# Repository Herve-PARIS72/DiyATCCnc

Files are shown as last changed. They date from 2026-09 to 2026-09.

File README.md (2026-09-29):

# DiyATCCnc

Prototype DIY de magasin linéaire à quatre douilles sur ressort pour une **CNC 3018**. Conception paramétrique OpenSCAD, fichiers STL et documentation en français.

**Version mécanique actuelle : V3. Les douilles restent entièrement sous le couvercle**, même au repos. Le couvercle laisse passer les écrous et retient les douilles. Les ressorts autorisent une descente de 4 mm, et des ergots internes empêchent la rotation des douilles.

> État réel : prototype d'ajustement manuel, pas un changeur automatique opérationnel. Les ressorts ne sont pas sélectionnés, le serrage n'est pas validé et aucune retenue de fraise desserrée n'est prévue. Ne pas lancer de serrage motorisé dans les pièces imprimées.

## Télécharger et ouvrir

- [Source OpenSCAD complet](cad/ATC_4_douilles_ressorts.scad)
- STL : [bloc](stl/bloc.stl), [couvercle](stl/plaque.stl), [douille](stl/douille.stl), [fond](stl/fond.stl)
- [Montage et impression](docs/MONTAGE.md)
- [Dimensions et ressorts](docs/CONCEPTION.md)
- [Matériel et intégration FluidNC](docs/ELECTRONIQUE.md)
- [Notice détaillée V3](docs/NOTICE_V3.txt)
- [Calibres pour l'écrou de 17 mm](calibres/)
- [Historique et limites](docs/HISTORIQUE.md)

Imprimer **1 bloc, 1 couvercle, 1 fond et 4 douilles**. Dans GitHub, les fichiers STL peuvent être visualisés individuellement ; utiliser le téléchargement du fichier pour les ouvrir dans un trancheur.

Dans OpenSCAD, modifier `piece` :

```scad
piece = "assemblage"; // Vue complète
// "coupe"      : coupe de contrôle de l'intérieur
// "bloc"       : corps seul
// "plaque"     : couvercle seul
// "douille"    : douille seule, à imprimer 4 fois
// "fond"       : fond avec guides de ressort et butées
// "impression" : toutes les pièces disposées à plat
```

Utiliser F5 pour l'aperçu et F6 avant export STL. Les ressorts affichés sont schématiques et ne sont pas exportés. Exporter les pièces séparément, pas l'assemblage en contact.

Pour montrer la position basse :

```scad
enfoncement = 4; // entre 0 et course
```

## Matériel déclaré

| Élément | Information connue |
|---|---|
| Machine | CNC 3018, variante exacte non documentée |
| Carte | ESP32, firmware FluidNC déclaré par l'utilisateur |
| Broche | Alimentation 24 V ; référence et courant à confirmer |
| Commande envisagée | Module double BTS7960 |
| Écrou | Clé de 17 mm, hauteur mesurée 13 mm |
| Ressorts | Pas encore achetés |

Le diamètre extérieur maximal de l'écrou, la hauteur de ses méplats et le dégagement du nez de broche restent à mesurer. Une clé de 17 mm ne suffit pas à définir tout le profil.

## Dimensions de la V3

| Dimension | Valeur de départ |
|---|---:|
| Ensemble fixe | 180 × 44 × 63 mm |
| Corps seul | 180 × 44 × 54 mm |
| Fond / couvercle | 6 / 3 mm |
| Entraxe outils | 40 mm |
| Course de chaque douille | 4 mm |
| Passage des écrous dans le couvercle | Ø22 mm, provisoire |
| Empreinte d'écrou | 17,4 mm sur plats, profondeur 13,5 mm |
| Fixation | 4 trous Ø5,5 mm, entraxes 166 × 28 mm |

Ces dimensions, hors mesures d'écrou confirmées, sont des hypothèses de prototype. Vérifier notamment la hauteur disponible en Z sur la machine.

## Reproduire les exports

Installer OpenSCAD et Python 3, puis depuis le dépôt :

```bash
python3 scripts/export_stl.py
python3 scripts/verifier_stl.py
```

Les scripts utilisent uniquement la bibliothèque standard Python et l'exécutable OpenSCAD. `OPENSCAD` peut désigner son chemin complet. Les contrôles de maillage ne prouvent ni la résistance des pièces ni le fonctionnement du serrage.

## Références

- [XATC — dépôt](https://github.com/xpix/XATC)
- [XATC — carrousel](https://github.com/xpix/XATC/wiki/XATC-Carousel)
- [BTS7960 — documentation Infineon](https://www.infineon.com/assets/row/public/documents/10/57/infineon-bts7960-ds-en.pdf)
- [FluidNC — dépôt officiel](https://github.com/bdring/FluidNC)
- [OpenSCAD](https://openscad.org/)

Le projet s'inspire de ces principes mais n'est ni affilié à RapidChange ni une reproduction validée de son mécanisme. Aucune licence tierce n'est attribuée automatiquement aux fichiers de ce dépôt ; le propriétaire peut choisir une licence de diffusion.

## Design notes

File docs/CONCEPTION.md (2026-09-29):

# Conception mécanique V3

## Fonctionnement

Le ressort pousse la douille contre le dessous du couvercle. L'ouverture du couvercle est plus petite que le diamètre extérieur de la douille et plus grande que l'écrou à engager. L'ergot coulisse dans une rainure interne : il bloque la rotation et autorise la translation verticale.

Le tube creux du fond centre le ressort, laisse passer la fraise et arrête la collerette après 4 mm de descente. La grande chambre inférieure permet l'insertion de la collerette par-dessous. Le guide supérieur est ajusté sur le corps de la douille.

Ce montage élastique traite une partie du problème d'engagement, mais **ne définit pas le mécanisme d'impact ni le contrôle du couple**. Ne pas assimiler le logement hexagonal fixe à une douille RapidChange fonctionnelle.

## Positions verticales

Origine Z au-dessous du fond :

| Élément | Au repos | À course maximale |
|---|---:|---:|
| Dessus du fond | 6 mm | 6 mm |
| Dessous de la collerette | 37 mm | 33 mm |
| Dessus de la collerette | 40 mm | 36 mm |
| Dessus de la douille | 60 mm | 56 mm |
| Dessous du couvercle | 60 mm | 60 mm |
| Dessus du couvercle | 63 mm | 63 mm |

Le changement de diamètre du guide est à Z=40,5 mm : 0,5 mm de jeu évite de faire de la collerette la butée haute. Le couvercle retient directement la face supérieure des douilles. La fraise peut dépasser sous le fond : prévoir une zone libre.

## Paramètres principaux

```scad
ecrou_plats = 17;
ecrou_hauteur = 13;
jeu_ecrou = 0.4;             // total sur plats
passage_ecrou = 22;          // à confirmer par mesure
passage_outil = 10;          // à adapter à la fraise
course = 4;
diam_douille = 28;
jeu_guidage = 0.4;           // jeu diamétral total
hauteur_douille = 23;
diam_collerette = 32;
ep_couvercle = 3;
```

L'écrou photographié comporte des zones cylindriques. Mesurer son diamètre maximal et la hauteur réelle des méplats avant de considérer l'empreinte hexagonale comme adaptée. Le diamètre de 19,5 mm indiqué dans une proposition de code n'a pas été confirmé par une mesure.

L'ouverture du couvercle est évasée à Ø23,6 mm sur les derniers 0,8 mm. Elle conserve Ø22 mm dans sa partie droite. La prise commence 3 mm sous la surface au repos et 7 mm en bas de course. Contrôler le nez de broche et la longueur réellement engagée : la hauteur de l'écrou seule ne garantit pas l'accès.

## Ressorts : réservation géométrique uniquement

| Paramètre proposé | Valeur |
|---|---:|
| Diamètre extérieur | 22 mm |
| Diamètre du fil | 2 mm |
| Diamètre intérieur calculé | 18 mm |
| Longueur libre | 33 mm |
| Longueur installée | 31 mm |
| Longueur en butée basse | 27 mm |
| Précompression | 2 mm |

Ce n'est pas une référence à acheter. La raideur `k` n'est pas choisie : pour un ressort linéaire, l'effort serait `2k` N au repos et `6k` N en butée, avec `k` en N/mm. Définir l'effort admissible avant sélection. Vérifier aussi longueur à spires jointives, guidage, fatigue et tolérances.

## Points restant à développer

- Maintien de la fraise lorsque la pince est desserrée.
- Engagement reproductible du filetage et de l'écrou, sans coincement.
- Transmission du couple et résistance des douilles/ergots : les pièces imprimées ne sont pas validées pour le serrage.
- Détection de présence et contrôle des échecs.
- Mesure de longueur après changement.
- Fixation adaptée aux rainures et courses effectives de la CNC 3018.
- Séquence de changement et intégration FluidNC après validation mécanique.

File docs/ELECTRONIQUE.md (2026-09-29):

# Électronique : état du projet

Matériel déclaré : carte ESP32 sous FluidNC, broche alimentée en 24 V, module double BTS7960 envisagé pour l'inversion d'un moteur DC à balais. La référence exacte du moteur, son courant et le brochage de la carte restent à confirmer.

La fiche Infineon indique une plage de fonctionnement de 5,5 à 27,5 V pour le BTS7960. Le 24 V déclaré est dans cette plage ; cela ne valide pas à lui seul le module complet, son refroidissement, les transitoires ou l'adéquation au moteur. Le « 43 A » commercial n'est pas une garantie de courant continu pour la carte vendue.

## Informations manquantes

- `config.yaml` FluidNC actuel et version installée.
- Référence/schéma de la carte et sorties logiques réellement disponibles.
- Brochage du module BTS7960 acheté et caractéristiques de ses entrées.
- Référence du moteur, courant de démarrage/blocage et aptitude au fonctionnement inverse.
- Palpeur de longueur, détection de présence et arrêt du cycle en cas d'échec.

Aucun GPIO, câblage fil à fil, fichier de configuration ou G-code n'est inventé dans ce dépôt. Ne pas brancher la sortie de puissance « SPINDLE » sur une entrée logique du BTS7960. La logique d'inversion doit prévoir l'arrêt avant changement de sens.

La compatibilité électrique ne valide pas le serrage mécanique. Le mécanisme de logement sur ressort ne fournit pas, seul, un contrôle de couple.

## Sources

- [Infineon BTS7960](https://www.infineon.com/assets/row/public/documents/10/57/infineon-bts7960-ds-en.pdf)
- [FluidNC](https://github.com/bdring/FluidNC)
- [RapidChange, exigences du magasin linéaire](https://rapidchangeatc.com/shop/automatic-tool-changer/linear-magazines/)

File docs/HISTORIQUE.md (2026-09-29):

# Historique de conception

- Calibres : ouvertures hexagonales 17,2 / 17,4 / 17,6 mm, pour essais statiques. Source et STL conservés dans `calibres/`.
- Premier bloc statique : 4 empreintes fixes, 180 × 40 × 30 mm, conservé dans `archives/bloc_statique/`. Ce n'est pas le montage à ressort actuel.
- V1 à ressort : douilles retenues par un épaulement intégré au corps.
- V2 : plaque supérieure démontable de 8 mm ; les douilles dépassaient de 12 mm. Cette disposition ne correspondait pas au besoin final.
- **V3 actuelle** : douilles entièrement sous le couvercle de 3 mm, ouvertures d'écrou Ø22 mm, rainures antirotation dans le corps. Course 4 mm. Hauteur totale 63 mm.

Les exports des V1/V2 à ressort ont été remplacés au fil des corrections ; ils ne sont pas présentés comme des fichiers historiques disponibles dans ce dépôt. Les dossiers principaux contiennent la V3.

## Validation effectuée

Les fichiers ont été calculés par OpenSCAD. Les maillages STL ont été contrôlés pour vérifier que chaque arête appartient à deux triangles. Les cotes verticales de repos et de course ont été vérifiées numériquement.

Il n'y a pas eu d'essai physique, de simulation d'efforts, de mesure de couple ou de validation de changement automatique. Un maillage fermé indique une propriété géométrique, pas une validation fonctionnelle.

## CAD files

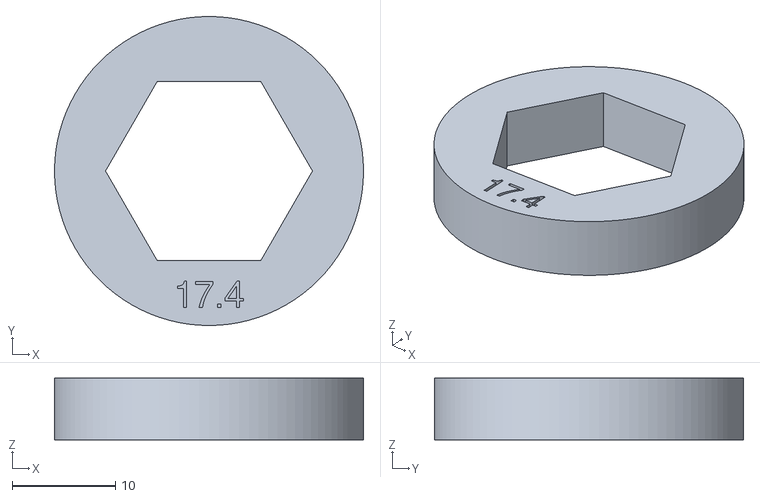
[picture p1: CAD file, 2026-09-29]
calibres/calibre_17_4.stl
30.0 x 30.0 x 6.00

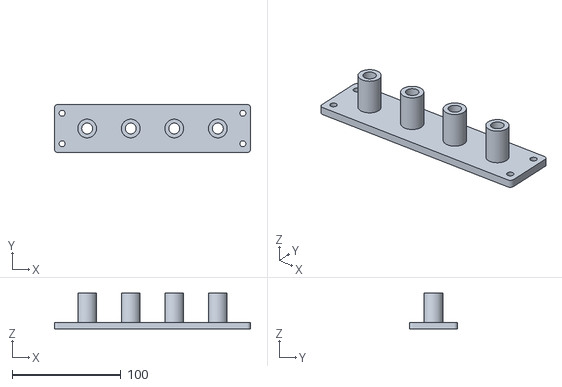
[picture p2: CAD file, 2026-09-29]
stl/fond.stl
180.0 x 44.0 x 33.0

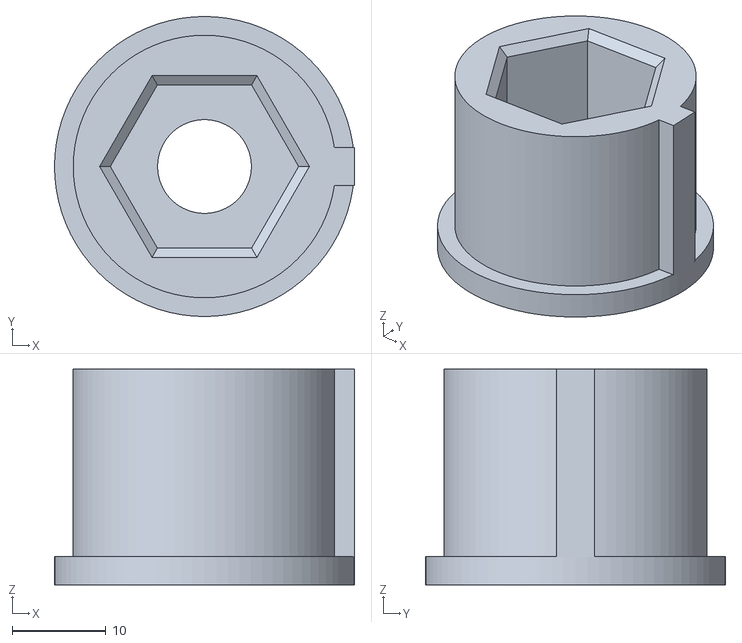
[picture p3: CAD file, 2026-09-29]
stl/douille.stl
32.0 x 32.0 x 23.0

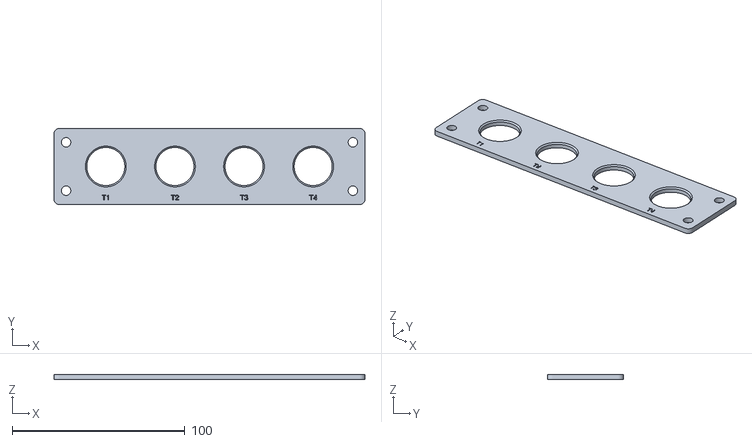
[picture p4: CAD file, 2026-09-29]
stl/plaque.stl
180.0 x 44.0 x 3.00

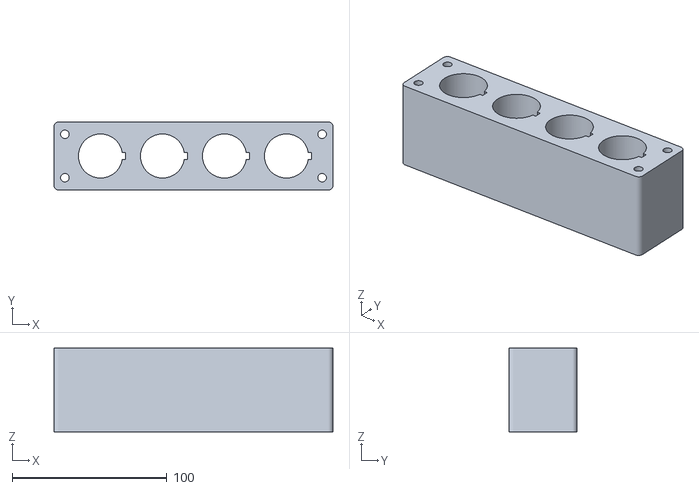
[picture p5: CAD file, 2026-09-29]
stl/bloc.stl
180.0 x 44.0 x 54.0

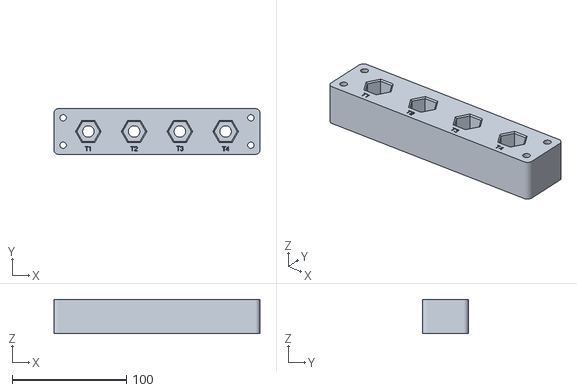
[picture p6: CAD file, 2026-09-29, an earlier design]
archives/bloc_statique/bloc_4_outils.stl
180.0 x 40.0 x 30.0

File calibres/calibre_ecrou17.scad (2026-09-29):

// CNC 3018 - calibres statiques, PAS une douille ATC fonctionnelle.
// Unites : mm. 17 mm sur plats confirmes ; hauteur ecrou 13 mm.
// L'ecrou reel peut etre cylindrique avec plats partiels : verifier l'engagement.
// selection = -1 : les trois calibres ; 0, 1, 2 : une piece.
selection = -1;
sur_plats = 17;
hauteur_ecrou = 13;
jeux = [0.2, 0.4, 0.6]; // jeu TOTAL sur plats, pas par face
hauteur_calibre = 6; // volontairement court pour sonder la zone des plats
$fn = 96;
module calibre(i) {
    ouverture = sur_plats + jeux[i];
    difference() {
        cylinder(d=30, h=hauteur_calibre);
        translate([0,0,-0.1])
            cylinder(d=ouverture/cos(30), h=hauteur_calibre+0.2, $fn=6);
        // Gravure de la largeur nominale sur plats
        translate([0,-12,hauteur_calibre-0.5])
            linear_extrude(height=0.6)
                text(str(ouverture),size=2.6,halign="center",valign="center");
    }
}
if (selection < 0) {
    for (i=[0:2]) translate([i*34,0,0]) calibre(i);
} else {
    assert(selection>=0 && selection<=2);
    calibre(selection);
}

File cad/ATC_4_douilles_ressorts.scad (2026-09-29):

/* CNC 3018 - prototype mecanique V3, douilles entierement sous le couvercle.
   Unites mm. Ecrou : 17 sur plats, hauteur 13.
   ATTENTION : prototype d'ajustement manuel, PAS un ATC valide.
   Ressorts, couple, maintien de fraise et profils reels restent a valider.
   Ne pas lancer de serrage motorise dans les empreintes imprimees.
   Inspiration : https://github.com/xpix/XATC
   https://rapidchangeatc.com/product-category/automatic-tool-changer/

   piece = "assemblage", "bloc", "douille", "fond", "plaque", "impression".
   F5 : apercu ; F6 : calcul ; exporter chaque piece separement en STL.
   Imprimer 1 bloc, 1 plaque, 1 fond et 4 douilles.
*/
piece = "assemblage";
$fn = 80;
nombre = 4;
entraxe = 40;
largeur = 44;
marge_extremite = 30;
rayon_coins = 3;

// Ecrou : seule la cote sur plats et sa hauteur sont confirmees.
ecrou_plats = 17;
ecrou_hauteur = 13;
jeu_ecrou = 0.4; // total sur plats
profondeur_empreinte = ecrou_hauteur + 0.5;
chanfrein = 1;
passage_outil = 10; // adapter au diametre de la fraise

// Douille et guidage (dimensions de prototype)
diam_douille = 28;
jeu_guidage = 0.4; // jeu diametral TOTAL
hauteur_douille = 23; // collerette comprise
diam_collerette = 32;
ep_collerette = 3;
diam_chambre = 34;
course = 4;
// Ergot axial : glisse dans une rainure et bloque la rotation.
largeur_ergot = 4;
saillie_ergot = 2;
jeu_ergot = 0.4;

// RESSORT PROVISOIRE : cotes reservees, pas une reference d'achat.
ressort_d_ext = 22;
ressort_fil = 2;
ressort_longueur_libre = 33;
precompression = 2;
// La raideur, la longueur a spires jointives et le couple restent a definir.

// Fond, guide superieur et fixation
ep_fond = 6;
ep_couvercle = 3;
passage_ecrou = 22; // provisoire : mesurer le diametre maximal reel
jeu_axial_collerette = 0.5; // le couvercle, et non la collerette, arrete la remontee
vis_d = 5.5; // 4 vis traversantes M5 + ecrous/rondelles externes
marge_vis_x = 7;
marge_vis_y = 8;
// Position de demonstration entre 0 (repos) et course.
enfoncement = 0;
afficher_ressorts = true;

longueur = (nombre-1)*entraxe + 2*marge_extremite;
ressort_longueur_installee = ressort_longueur_libre-precompression;
z_collerette = ep_fond + ressort_longueur_installee;
z_epaulement = z_collerette + ep_collerette + jeu_axial_collerette;
z_couvercle = z_collerette + hauteur_douille;
hauteur_totale_bloc = z_couvercle + ep_couvercle;
rayon_ergot_ext = diam_douille/2 + saillie_ergot;

assert(nombre>=1 && floor(nombre)==nombre);
assert(enfoncement>=0 && enfoncement<=course);
assert(ressort_longueur_installee>course);
assert(ressort_d_ext < diam_collerette);
assert(ressort_d_ext-2*ressort_fil > passage_outil+2);
assert(diam_collerette > diam_douille+jeu_guidage+2);
assert(diam_chambre > diam_collerette+0.4);
assert(entraxe > diam_chambre+3);
assert(largeur > diam_chambre+6);
assert(hauteur_douille-profondeur_empreinte>ep_collerette);
assert(diam_douille > (ecrou_plats+jeu_ecrou+2*chanfrein)/cos(30)+3);
assert(hauteur_douille-ep_collerette-jeu_axial_collerette>course);
assert(passage_ecrou > (ecrou_plats+jeu_ecrou)/cos(30));
assert(passage_ecrou < diam_douille-3);
assert(ep_couvercle>0);

function position(i) = (i-(nombre-1)/2)*entraxe;
module arrondi(l,p,h) {
 linear_extrude(height=h)
  offset(r=rayon_coins)
   square([l-2*rayon_coins,p-2*rayon_coins],center=true);
}
module trous_vis(h) {
 for(x=[-longueur/2+marge_vis_x,longueur/2-marge_vis_x])
  for(y=[-largeur/2+marge_vis_y,largeur/2-marge_vis_y])
   translate([x,y,-0.1]) cylinder(d=vis_d,h=h+0.2);
}
module empreinte_hex(af,h) { cylinder(d=af/cos(30),h=h,$fn=6); }

// Corps haut : insertion des douilles par DESSOUS (collerettes).
// Le guidage et la rainure antirotation sont entierement sous le couvercle.
module bloc() {
 h=z_couvercle-ep_fond;
 difference() {
  arrondi(longueur,largeur,h);
  trous_vis(h);
  for(i=[0:nombre-1]) translate([position(i),0,0]) {
   translate([0,0,-0.1])
    cylinder(d=diam_chambre,h=z_epaulement-ep_fond+0.1);
   translate([0,0,-0.1]) cylinder(d=diam_douille+jeu_guidage,h=h+0.2);
   translate([0,-(largeur_ergot+jeu_ergot)/2,-0.1])
    cube([rayon_ergot_ext+jeu_ergot/2,largeur_ergot+jeu_ergot,h+0.2]);
  }
 }
}

// Couvercle : ouvertures pour ECROUS uniquement, pas pour les douilles.
// Sa face inferieure retient directement le dessus des douilles.
module plaque() {
 difference() {
  arrondi(longueur,largeur,ep_couvercle);
  trous_vis(ep_couvercle);
  for(i=[0:nombre-1]) translate([position(i),0,0]) {
   translate([0,0,-0.1]) cylinder(d=passage_ecrou,h=ep_couvercle+0.2);
   translate([0,0,ep_couvercle-0.8])
    cylinder(d1=passage_ecrou,d2=passage_ecrou+1.6,h=0.81);
   translate([0,-18,ep_couvercle-0.6]) linear_extrude(height=0.7)
    text(str("T",i+1),size=3,halign="center",valign="center");
  }
 }
}

// Douille exportee avec collerette sur le plateau d'impression.
module douille() {
 difference() {
  union() {
   cylinder(d=diam_collerette,h=ep_collerette);
   translate([0,0,ep_collerette-0.01])
    cylinder(d=diam_douille,h=hauteur_douille-ep_collerette+0.01);
   translate([diam_douille/2-1,-largeur_ergot/2,ep_collerette-0.01])
    cube([saillie_ergot+1,largeur_ergot,hauteur_douille-ep_collerette+0.01]);
  }
  translate([0,0,-0.1]) cylinder(d=passage_outil,h=hauteur_douille+0.2);
  translate([0,0,hauteur_douille-profondeur_empreinte])
   empreinte_hex(ecrou_plats+jeu_ecrou,profondeur_empreinte+0.1);
  translate([0,0,hauteur_douille-chanfrein])
   cylinder(d1=(ecrou_plats+jeu_ecrou)/cos(30),
            d2=(ecrou_plats+jeu_ecrou+2*chanfrein)/cos(30),
            h=chanfrein+0.01,$fn=6);
 }
}

// Fond avec centrage annulaire du ressort et butee de course centrale.
// La butee touche la collerette apres "course" mm d'enfoncement.
module fond() {
 difference() {
  union() {
   arrondi(longueur,largeur,ep_fond);
   for(i=[0:nombre-1]) translate([position(i),0,ep_fond-0.01]) {
    // Tube central : centre le ressort et limite la descente.
    cylinder(d=ressort_d_ext-2*ressort_fil-0.8,
             h=ressort_longueur_installee-course+0.01);
   }
  }
  trous_vis(hauteur_totale_bloc);
  for(i=[0:nombre-1]) translate([position(i),0,-0.1])
   cylinder(d=passage_outil,h=hauteur_totale_bloc+0.2);
 }
}

// Ressorts SCHEMATIQUES, affiches uniquement en apercu, jamais en STL.
// Anneaux de visualisation : ne representent pas la geometrie a fabriquer.
module ressort_apercu(h) {
 for(j=[0:6]) translate([0,0,ressort_fil/2+j*(h-ressort_fil)/6])
  rotate_extrude($fn=48)
   translate([(ressort_d_ext-ressort_fil)/2,0]) circle(d=ressort_fil,$fn=12);
}
module assemblage() {
 color("SteelBlue",0.45) translate([0,0,ep_fond]) bloc();
 color("DimGray") fond();
 color("LightSteelBlue") translate([0,0,z_couvercle]) plaque();
 for(i=[0:nombre-1]) {
  color("Orange") translate([position(i),0,z_collerette-enfoncement]) douille();
  if($preview && afficher_ressorts)
   %translate([position(i),0,ep_fond])
    ressort_apercu(ressort_longueur_installee-enfoncement);
 }
}
if(piece=="bloc") bloc();
else if(piece=="fond") fond();
else if(piece=="plaque") plaque();
else if(piece=="douille") douille();
else if(piece=="impression") {
 bloc();
 translate([0,largeur+10,0]) fond();
 translate([0,2*(largeur+10),0]) plaque();
 for(i=[0:nombre-1]) translate([position(i),-largeur-2,0]) douille();
}
else if(piece=="coupe") difference() {
 assemblage();
 translate([-longueur,-largeur,-1]) cube([2*longueur,largeur,hauteur_totale_bloc+10]);
}
else if(piece=="assemblage") assemblage();
else assert(false,"piece inconnue");

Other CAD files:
calibres/calibre_17_2.stl
calibres/calibre_17_6.stl
archives/bloc_statique/bloc_4_outils.scad

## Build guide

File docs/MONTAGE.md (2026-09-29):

# Impression et montage

## Nomenclature

| Pièce | Quantité | Fichier ou état |
|---|---:|---|
| Corps | 1 | `stl/bloc.stl` |
| Couvercle | 1 | `stl/plaque.stl` |
| Fond avec tubes de guidage | 1 | `stl/fond.stl` |
| Douille | 4 | `stl/douille.stl` |
| Ressort de compression | 4 | À sélectionner, voir CONCEPTION.md |
| Vis M5, écrous, rondelles | 4 jeux | Passage Ø5,5, longueur de serrage 63 mm hors quincaillerie/support |
| Fixation machine | Selon montage | À adapter au plateau réel |

Les vis traversantes solidarisent les trois niveaux. Leur longueur exacte dépend des rondelles, écrous et de la fixation machine. Elles ne sont pas représentées dans le source.

## Impression

Commencer par les calibres dans `calibres/`. Choisir l'ouverture qui entre sans forcer, puis reporter le jeu dans le source. Si la partie ronde de l'écrou bloque l'insertion, modifier son profil après mesure, pas seulement le jeu.

Pour les premiers essais dimensionnels : couche 0,2 mm, 4 à 6 périmètres, ajuster selon imprimante et matériau. Cela ne constitue pas une spécification de résistance au serrage.

- Douilles : collerette à plat sur le plateau.
- Fond : plaque à plat, tubes vers le haut.
- Couvercle : face inférieure à plat.
- Bloc : face inférieure à plat ; vérifier le surplomb interne de 2,8 mm sous le guide, ajouter des supports locaux si nécessaire et les retirer complètement.

Les jeux sont des hypothèses : contrôler le coulissement sur une douille avant d'imprimer tout l'ensemble.

## Montage hors tension

1. Introduire les douilles par le dessous du corps : les collerettes ne passent pas à travers le guide supérieur.
2. Aligner les ergots dans les rainures internes.
3. Placer les ressorts choisis autour des tubes du fond.
4. Positionner le fond et fermer le dessus par le couvercle.
5. Monter les quatre vis traversantes avec écrous et rondelles, sans déformer le bloc.
6. Vérifier manuellement le retour contre le couvercle et la course jusqu'aux butées du fond.
7. Approcher l'écrou hors tension, contrôler le passage et le dégagement de la broche.

Soutenir le fond au démontage : les mêmes vis maintiennent l'ensemble. Les ressorts sont préchargés une fois montés. Aucun outil coupant n'est nécessaire pour le premier essai de mouvement.

## Vérifications avant toute évolution

Les douilles ne doivent pas dépasser le dessous du couvercle au repos. Les ergots doivent rester engagés pendant toute la course. Contrôler que le ressort n'arrive pas à spires jointives avant la butée.

Le trou central n'assure aucune retenue d'une fraise desserrée. Prévoir une solution dédiée avant un essai automatique. Le prototype actuel doit rester en essais manuels ; il ne fournit aucune validation du couple de serrage.

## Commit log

2026-09-29 Documente le prototype ATC V3
2026-09-29 Ajoute le source OpenSCAD V3
    [ATC_4_douilles_ressorts.scad]
2026-09-29 Ajoute les quatre pieces STL du prototype V3
    [bloc.stl, douille.stl, fond.stl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]
2026-09-29 Ajoute les explications et instructions de montage
2026-09-29 Ajoute les calibres de controle de l ecrou
    [calibre_17_2.stl, calibre_17_4.stl, calibre_17_6.stl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]
2026-09-29 Ajoute les scripts d export et de verification des STL
2026-09-29 Archive le premier bloc statique
    [bloc_4_outils.scad, bloc_4_outils.stl]
